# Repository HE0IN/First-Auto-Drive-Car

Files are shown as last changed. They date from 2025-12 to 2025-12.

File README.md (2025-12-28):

# 🚗 First-Auto-Drive-Car

카메라 영상과 조이스틱 입력값을 학습하여 자율주행하는 RC카 프로젝트

> 전남대학교 전자통신공학부 학부 프로젝트 (2022.09 ~ 2022.12)

---

## 📌 프로젝트 소개

사람이 PS4 조이스틱으로 RC카를 조작할 때의 **카메라 영상**과 **조향/속도값**을 수집하고, 이를 TensorFlow CNN 모델로 학습시켜 카메라 영상만으로 자율주행이 가능한 RC카를 개발했습니다.

차체 외관은 Autodesk Fusion 360으로 직접 설계하고 3D 프린팅으로 제작했습니다.

---

## ✨ 주요 기능

- **데이터 수집** - PS4 조이스틱 조작 시 카메라 영상과 조향/속도값을 동시에 저장
- **데이터 밸런싱** - 직진 데이터 과다 수집 문제 해결을 위한 샘플링
- **이미지 증강** - Pan, Zoom, Brightness 랜덤 적용으로 학습 데이터 다양화
- **End-to-End 학습** - NVIDIA 자율주행 모델 아키텍처 기반 CNN 구현
- **실시간 자율주행** - 학습된 모델로 카메라 영상 기반 조향/속도 제어
- **안전 기능** - 초음파 센서 장애물 감지 및 빨간색 정지신호 인식

---

## 🛠 Tech Stack

| 분류 | 기술 |
|:---:|:---|
| **Hardware** | Raspberry Pi 4, Pi Camera, DC Motor, L298N Driver, PS4 Controller, HC-SR04 Ultrasonic |
| **AI/ML** | TensorFlow, Keras, NumPy, OpenCV, imgaug |
| **Language** | Python |
| **Design** | Autodesk Fusion 360, 3D Printing |

---

## 📁 파일 구조

```
First-Auto-Drive-Car/
│
├── 🎮 데이터 수집 (라즈베리파이)
│   ├── DataCollectionMain.py     # 데이터 수집 메인 실행
│   ├── DataCollectionModule.py   # 이미지/CSV 저장 모듈
│   ├── JoyStickModule.py         # PS4 조이스틱 입력 처리
│   ├── MotorModule.py            # DC 모터 PWM 제어
│   └── WebcamModule.py           # 카메라 영상 캡처
│
├── 🧠 모델 학습 (PC)
│   ├── Training.py               # 모델 학습 실행
│   ├── Training_Add.py           # 기존 모델에 추가 학습
│   ├── utils.py                  # 데이터 로드, 전처리, 모델 정의
│   └── utils_Add.py              # 추가 학습용 유틸리티
│
├── 🚗 자율주행 실행 (라즈베리파이)
│   ├── RunMain.py                # 자율주행 실행 (기본)
│   ├── Final.py                  # 자율주행 실행 (최종) - 초음파/정지신호 감지
│   ├── WebcamModule_Final.py     # 카메라 + 빨간색 정지신호 감지
│   └── testmodel.py              # 모델 테스트용
│
└── 📂 data/                      # 수집된 학습 데이터
    ├── IMG0/, IMG1/, ...             # 이미지 폴더
    └── log_0.csv, log_1.csv, ...     # 조향/속도 레이블
```

---

## 📄 파일별 설명

### 🎮 데이터 수집

| 파일 | 설명 |
|:---|:---|
| `DataCollectionMain.py` | 데이터 수집 메인 실행 파일. 조이스틱 입력을 받아 모터를 제어하고, Share 버튼으로 녹화 시작/종료 |
| `DataCollectionModule.py` | 이미지를 폴더에 저장하고 조향/속도값을 CSV로 기록 |
| `JoyStickModule.py` | pygame 기반 PS4 조이스틱 입력 처리. X/O/△/□로 속도 단계 조절 |
| `MotorModule.py` | L298N 모터 드라이버 PWM 제어. 조향값과 속도를 좌/우 모터 출력으로 변환 |
| `WebcamModule.py` | OpenCV로 카메라 영상 캡처 및 리사이즈 |

### 🧠 모델 학습

| 파일 | 설명 |
|:---|:---|
| `Training.py` | 처음부터 새 모델 학습. 데이터 경로, 로그 인덱스, 모델명 설정 |
| `Training_Add.py` | 기존 학습된 모델(.h5)에 추가 데이터로 Fine-tuning |
| `utils.py` | 핵심 유틸리티 - 데이터 로드, 밸런싱, 이미지 증강, 전처리, CNN 모델 생성 |

### 🚗 자율주행 실행

| 파일 | 설명 |
|:---|:---|
| `RunMain.py` | 기본 자율주행 실행. 카메라 → 모델 예측 → 모터 제어 |
| `Final.py` | 최종 자율주행. 초음파 센서(30cm 장애물 감지) + 빨간색 정지신호 인식 추가 |
| `WebcamModule_Final.py` | HSV 색공간에서 빨간색 객체 감지 기능이 추가된 카메라 모듈 |

---

## 🔄 시스템 파이프라인

```
┌─────────────────────────────────────────────────────────────────┐
│                    1. 데이터 수집 (라즈베리파이)                    │
├─────────────────────────────────────────────────────────────────┤
│                                                                 │
│   python DataCollectionMain.py                                  │
│                                                                 │
│   • PS4 조이스틱으로 RC카 조작                                    │
│   • Share 버튼: 녹화 시작/종료                                    │
│   • X/O/△/□: 속도 단계 (0.4 / 0.6 / 0.8 / 1.0)                  │
│   • 출력: IMG폴더 + log.csv                                      │
│                                                                 │
└─────────────────────────────────────────────────────────────────┘
                               ▼
┌─────────────────────────────────────────────────────────────────┐
│                       2. 모델 학습 (PC)                          │
├─────────────────────────────────────────────────────────────────┤
│                                                                 │
│   python Training.py                                            │
│                                                                 │
│   • 데이터 로드 및 밸런싱                                         │
│   • 이미지 증강 (Pan, Zoom, Brightness)                          │
│   • 전처리: RGB→YUV, GaussianBlur, Resize(200x66)               │
│   • CNN 학습 (NVIDIA End-to-End 아키텍처)                        │
│   • 출력: model.h5                                               │
│                                                                 │
└─────────────────────────────────────────────────────────────────┘
                               ▼
┌─────────────────────────────────────────────────────────────────┐
│                    3. 자율주행 (라즈베리파이)                       │
├─────────────────────────────────────────────────────────────────┤
│                                                                 │
│   python Final.py                                               │
│                                                                 │
│   • 카메라 영상 → 전처리 → 모델 예측                               │
│   • 예측값: [Steering, Throttle] → 모터 제어                      │
│   • 초음파: 30cm 이내 장애물 → 정지                                │
│   • 색상: 빨간색 정지신호 → 정지                                   │
│                                                                 │
└─────────────────────────────────────────────────────────────────┘
```

---

## 🧠 모델 아키텍처

NVIDIA End-to-End Learning 논문 기반 CNN 모델

```
Input: (66, 200, 3)
        │
        ▼
┌───────────────────┐
│ Conv2D 24 (5x5)   │ stride=2, ELU
└─────────┬─────────┘
          ▼
┌───────────────────┐
│ Conv2D 36 (5x5)   │ stride=2, ELU, Dropout(0.2)
└─────────┬─────────┘
          ▼
┌───────────────────┐
│ Conv2D 48 (5x5)   │ stride=2, ELU
└─────────┬─────────┘
          ▼
┌───────────────────┐
│ Conv2D 64 (3x3)   │ ELU
└─────────┬─────────┘
          ▼
┌───────────────────┐
│ Conv2D 64 (3x3)   │ ELU
└─────────┬─────────┘
          ▼
┌───────────────────┐
│     Flatten       │
└─────────┬─────────┘
          ▼
┌───────────────────┐
│ Dense 100         │ ELU, Dropout(0.3)
└─────────┬─────────┘
          ▼
┌───────────────────┐
│ Dense 50          │ ELU
└─────────┬─────────┘
          ▼
┌───────────────────┐
│ Dense 10          │ ELU
└─────────┬─────────┘
          ▼
┌───────────────────┐
│ Dense 2           │ Output: [Steering, Throttle]
└───────────────────┘
```

---

## 🚀 실행 방법

### 환경 설정

**라즈베리파이**
```bash
pip install opencv-python numpy tensorflow pygame RPi.GPIO
```

**PC (학습용)**
```bash
pip install tensorflow opencv-python numpy pandas matplotlib scikit-learn imgaug
```

### 1. 데이터 수집

```bash
# 라즈베리파이에서 실행
python DataCollectionMain.py
```

### 2. 모델 학습

```bash
# PC에서 실행
python Training.py
```

`Training.py` 설정:
```python
data_path = "your/data/path"      # 데이터 경로
data_index = [0, 9]               # 로그 파일 범위 (log_0 ~ log_9)
new_model_name = 'model.h5'       # 저장할 모델명
```

### 3. 자율주행

```bash
# 라즈베리파이에서 실행
python Final.py
```

`Final.py` 설정:
```python
model = load_model('/path/to/model.h5')
throttleSen = 0.525    # 속도 민감도
steeringSen = 0.225    # 조향 민감도
```

---

## 🔧 하드웨어 핀 연결

| 모듈 | GPIO |
|:---:|:---:|
| Motor ENA | 0 |
| Motor IN1A | 6 |
| Motor IN2A | 5 |
| Motor ENB | 26 |
| Motor IN1B | 19 |
| Motor IN2B | 13 |
| Ultrasonic TRIG | 23 |
| Ultrasonic ECHO | 24 |

---

## 📝 배운 점

- 임베디드 환경에서의 딥러닝 모델 배포 및 최적화
- End-to-End Learning 방식의 자율주행 시스템 이해
- 실시간 영상 처리와 하드웨어 제어의 동기화
- 데이터 불균형 문제 해결 (직진 데이터 언더샘플링)
- Autodesk Fusion 360을 활용한 3D 모델링 및 프린팅

---

## 📄 License

This project is licensed under the MIT License.

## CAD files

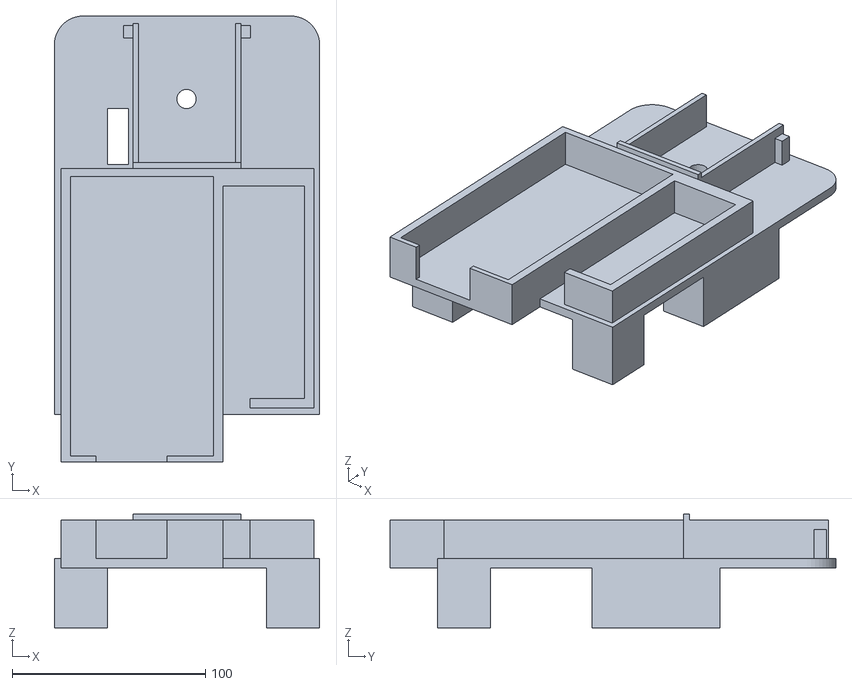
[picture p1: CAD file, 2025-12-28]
사물인터넷 3D/2층 카메라 구멍.stl
137.5 x 231.0 x 59.0

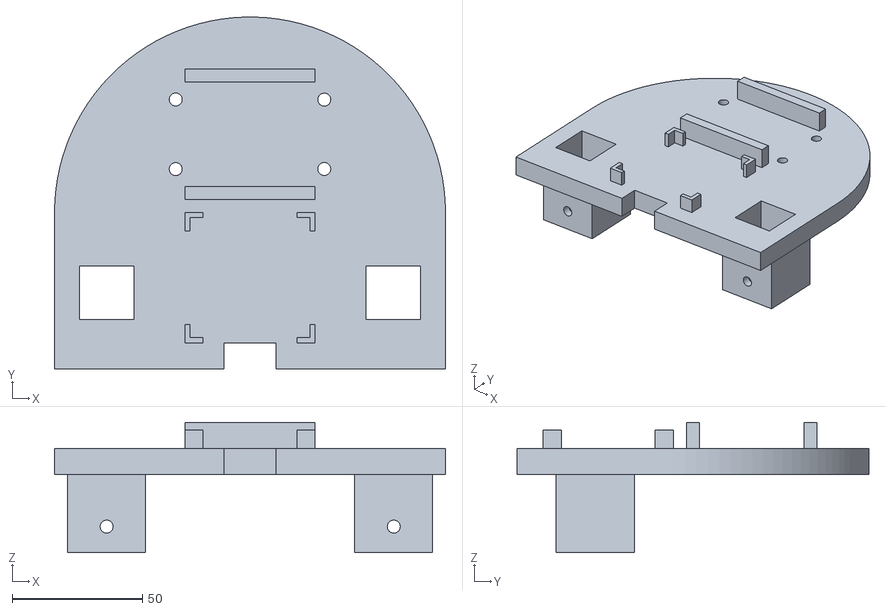
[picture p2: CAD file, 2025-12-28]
사물인터넷 3D/앞본체 바꿈.stl
150.0 x 135.0 x 50.0

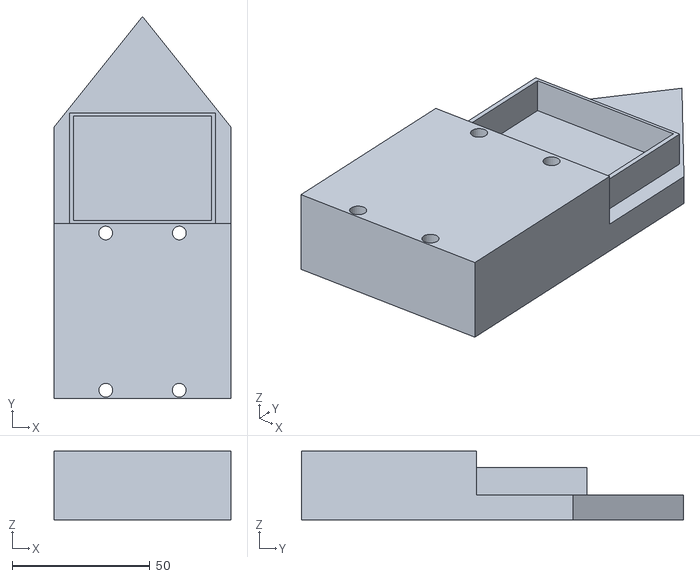
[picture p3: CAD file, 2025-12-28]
사물인터넷 3D/초음파 바구니.stl
64.0 x 138.5 x 25.0

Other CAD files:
사물인터넷 3D/2층 카메라 입구 마지막 수정.stl

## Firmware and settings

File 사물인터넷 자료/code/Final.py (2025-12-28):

import cv2
import numpy as np
import os
import tensorflow
from tensorflow.keras.models import load_model
import WebcamModule_Final as wM
import MotorModule as mM
import time
import RPi.GPIO as GPIO
GPIO.setmode(GPIO.BCM)

############### Ultra Sonic ###############
TRIG=23
ECHO=24

GPIO.setup(TRIG,GPIO.OUT)
GPIO.setup(ECHO, GPIO.IN)
#######################################

throttleSen = 0.525
steeringSen = 0.225  # Steering Sensitivity
motor= mM.Motor(0,6,5,26,19,13)#Pin Numbers
model = load_model('/home/pi/example/ai/12210130.h5')

def preProcess(img):
    img = img[:, :, :]
    img = cv2.cvtColor(img, cv2.COLOR_RGB2YUV)
    img = cv2.GaussianBlur(img, (11, 11), 0)
    img = cv2.resize(img, (200, 66))
    img = img / 255
    return img

while True:
    GPIO.output(TRIG, False)
    time.sleep(0.0001)

    GPIO.output(TRIG, True)
    time.sleep(0.0001)
    GPIO.output(TRIG, False)
    while GPIO.input(ECHO)==0:
        pulse_start = time.time()

    while GPIO.input(ECHO)==1:
        pulse_end = time.time()

    pulse_duration = pulse_end - pulse_start
    distance = pulse_duration *17150
    distance = round(distance, 2)


    img, StopSign= wM.getImg(True, size=[240, 120])
    img = np.asarray(img)
    img = preProcess(img)
    img = np.array([img])
    pred = model.predict(img)
    print(pred)

    motor.move(-pred[0][1]*throttleSen, pred[0][0]*steeringSen)

    if distance < 30 | int(StopSign) > 1:
        print("Stop")
        motor.move(0,0)
    else:
        print("Go!!")
    cv2.waitKey(1)

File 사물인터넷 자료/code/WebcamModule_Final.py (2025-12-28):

import cv2
import numpy as np

cap = cv2.VideoCapture(0)

def getImg(display= False,size=[240,120]):
    _, imageFrame = cap.read()
    imageFrame = cv2.resize(imageFrame,(size[0],size[1]))
    hsvFrame = cv2.cvtColor(imageFrame, cv2.COLOR_BGR2HSV)

    red_lower = np.array([136, 87, 111], np.uint8)
    red_upper = np.array([180,255,255], np.uint8)
    red_mask = cv2.inRange(hsvFrame, red_lower, red_upper)

    green_lower = np.array([25, 52, 72], np.uint8)
    green_upper = np.array([102, 255, 255], np.uint8)
    green_mask = cv2.inRange(hsvFrame, green_lower, green_upper)

    blue_lower = np.array([94,80,2], np.uint8)
    blue_upper = np.array([120, 255, 255], np.uint8)
    blue_mask = cv2.inRange(hsvFrame, blue_lower,blue_upper)

    kernal = np.ones((5,5), "uint8")

    red_mask = cv2.dilate(red_mask, kernal)
    res_red = cv2.bitwise_and(imageFrame, imageFrame, mask = red_mask)

    green_mask = cv2.dilate(green_mask, kernal)
    res_green = cv2.bitwise_and(imageFrame, imageFrame, mask = green_mask)

    blue_mask = cv2.dilate(red_mask, kernal)
    res_blue = cv2.bitwise_and(imageFrame, imageFrame, mask = blue_mask)

    StopSign=0.1
    # creating contour to track red color
    contours, hierarchy = cv2.findContours(red_mask, cv2.RETR_TREE, cv2.CHAIN_APPROX_SIMPLE)

    for pic, contour in enumerate(contours):
        area = cv2.contourArea(contour)
        if(area > 300):
            x,y,w,h = cv2.boundingRect(contour)
            imageFrame = cv2.rectangle(imageFrame, (x,y), (x+w,y+h), (0,0,255),2)
            Text=cv2.putText(imageFrame, "RED", (x,y), cv2.FONT_HERSHEY_SIMPLEX, 1.0,(0,0,255) )
            StopSign = Text[0][0][0]
            #print(StopSign)

    # creating contour to track green color
    contours, hierarchy = cv2.findContours(green_mask, cv2.RETR_TREE, cv2.CHAIN_APPROX_SIMPLE)

    #for pic, contour in enumerate(contours):
    #    area = cv2.contourArea(contour)
    #    if(area > 300):
    #        x,y,w,h = cv2.boundingRect(contour)
    #        imageFrame = cv2.rectangle(imageFrame, (x,y), (x+w,y+h), (0,255,0),2)
    #        cv2.putText(imageFrame, "Green Color", (x,y), cv2.FONT_HERSHEY_SIMPLEX, 1.0,(0,255,0))


    # creating contour to track blue color
    contours, hierarchy = cv2.findContours(blue_mask, cv2.RETR_TREE, cv2.CHAIN_APPROX_SIMPLE)

    #for pic, contour in enumerate(contours):
    #    area = cv2.contourArea(contour)
    #    if(area > 300):
    #        x,y,w,h = cv2.boundingRect(contour)
    #        imageFrame = cv2.rectangle(imageFrame, (x,y), (x+w,y+h), (255,0,0),2)
    #        cv2.putText(imageFrame, "blue Color", (x,y), cv2.FONT_HERSHEY_SIMPLEX, 1.0,(255,0,0))


    #cv2.imshow("Multiple Color Detection in Real-Time", imageFrame)

    if display:
        cv2.imshow('IMG',imageFrame)
    return imageFrame, StopSign

if __name__ == '__main__':
    while True:
        imageFrame, StopSign = getImg(True)
